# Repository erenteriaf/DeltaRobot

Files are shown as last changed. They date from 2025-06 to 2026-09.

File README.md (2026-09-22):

# Delta Robot: Vision-Guided Parallel Manipulator

A three-axis delta robot designed, machined, and programmed from scratch. A Cognex camera on the end effector reads a tic-tac-toe board, a Python game layer chooses the move, and a Siemens S7-1200 PLC executes it through closed-form inverse kinematics. The result is an autonomous robot that plays tic-tac-toe against a human.

Delta Tec Challenge, *Design and Development of Robots*, Tecnológico de Monterrey, February to June 2025. Team of six.

<!-- Replace with a photo or GIF of the physical robot playing -->
<!-- ![Delta robot playing tic-tac-toe](docs/demo.gif) -->

## System overview

```mermaid
flowchart LR
    CAM[Cognex camera] -- TCP socket --> PY[Python game layer<br/>minimax]
    PY -- S7 protocol via snap7<br/>target XYZ, gripper, conveyor --> PLC[Siemens S7-1200<br/>IK in SCL]
    PLC -- pulse trains --> M[3x NEMA 23 geared steppers]
    LS[Limit switches] --> PLC
    M --> R[Delta mechanism + pneumatic gripper]
```

Perception and decision making run on a PC; everything that touches the motors (kinematics, homing, motion commands) runs deterministically on the PLC. The PC only writes a Cartesian target and a few flags to a PLC data block.

## Mechanical design

Designed in SolidWorks and manufactured in-house on a Haas VF-4 CNC mill and a lathe.

| Subsystem | Implementation |
|---|---|
| Structure | Base, biceps, motor mounts, and end-effector platform CNC-cut from 1/2 in aluminum plate |
| Actuation | NEMA 23 steppers (3 N·m) with SPLF60 5:1 planetary gearboxes, one per arm |
| Shoulder joint | Oldham coupling into a lathe-turned aluminum shaft supported by an SHF-14 crossed-roller bearing, which carries the arm's moment loads instead of the gearbox |
| Forearms | Parallel pairs of 10 mm aluminum rods with left- and right-hand threaded M6 rod ends, so each forearm's length can be trimmed by rotating the rod |
| End effector | Pneumatic gripper and Cognex camera mounted on the moving platform |
| Safety and sensing | Roller-lever limit switch per arm for homing, emergency stop, thermomagnetic breaker |

With 1/16 microstepping and the 5:1 gearbox, each arm has 16,000 steps per revolution, a joint resolution of 0.0225°.

A static FEA of the full assembly (551 contact sets) under a 2 kg payload gave a maximum resultant displacement of about 0.12 mm.

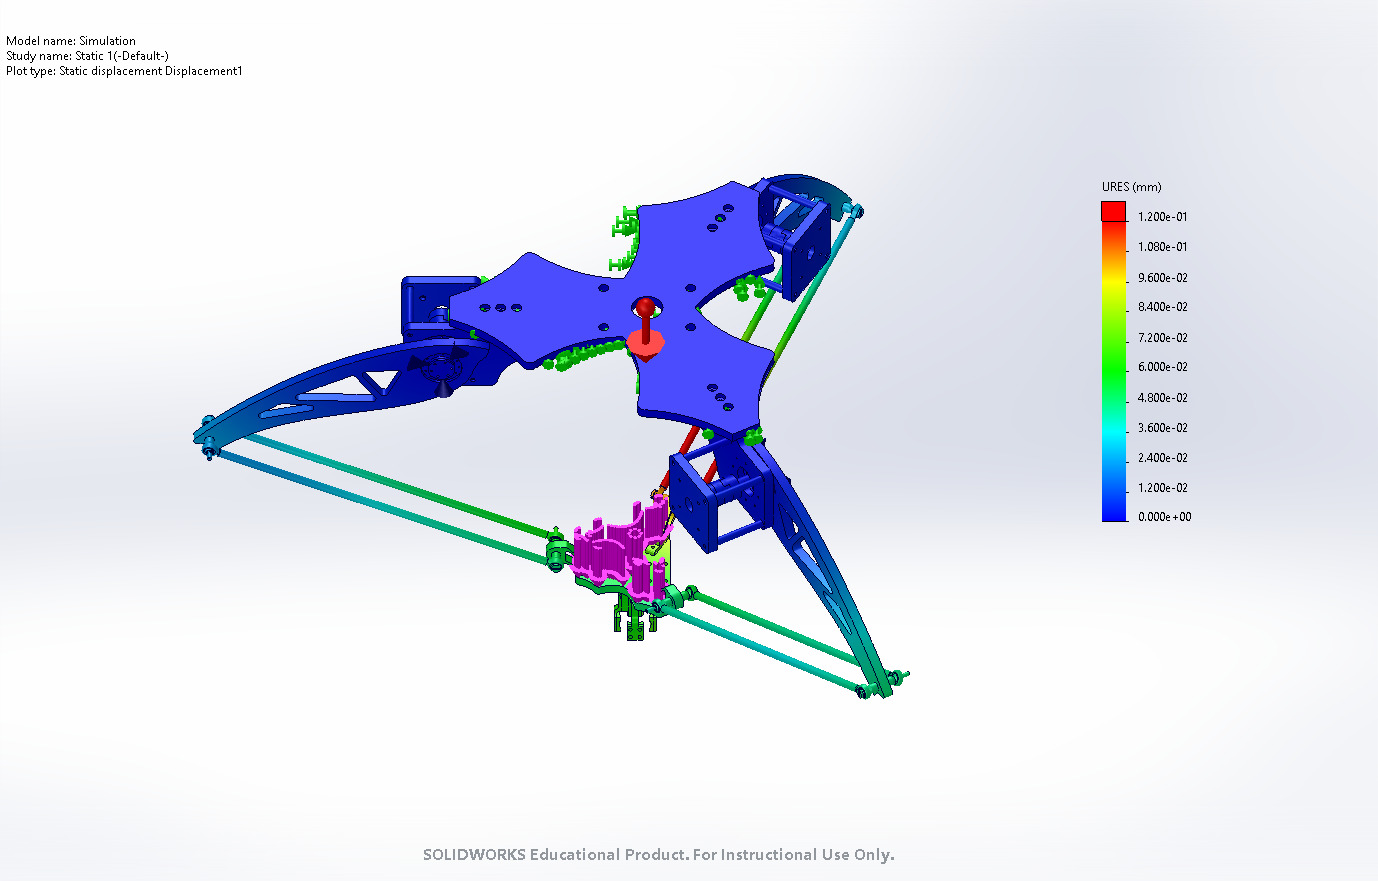
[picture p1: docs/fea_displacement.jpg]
Static FEA displacement plot


## Kinematics

| Parameter | Value |
|---|---|
| Base radius (center to biceps axis), $\rho_B$ | 215.8 mm |
| Biceps length, $l_1$ | 320 mm |
| Forearm length (rod-end center to center), $l_2$ | 476 mm |
| Platform radius, $\rho_P$ | 100 mm |

Three MATLAB models in `kinematics/`, each a runnable script that prints its result and draws the robot: `DeltaRobotInvKinematics.m`, `DeltaRobotFwdKinematics.m` and `DeltaRobotWorkspace.m`.

### Inverse kinematics

Solved in closed form, arm by arm, which is what makes it portable to a PLC scan. For arm *i*, the target platform joint is rotated into that arm's plane (0°, 120°, 240° about *z*). The forearm, a sphere of radius $l_2$ around the platform joint, cuts that plane in a circle of radius

$$\phi_i = \sqrt{l_2^2 - x_i^2}$$

where $x_i$ is the out-of-plane offset. The elbow is the intersection of this circle with the biceps circle of radius $l_1$ around the shoulder, and the crank angle follows from the elbow position:

$$\theta_i = \mathrm{atan2}\left(z_{J_i}, y_{B_i} - y_{J_i}\right)$$

Two intersections exist; the one with the smallest $y$ is the outward elbow the machine is built in. Targets where the circles do not intersect are rejected as unreachable, which is the same test the workspace sweep below is built on.

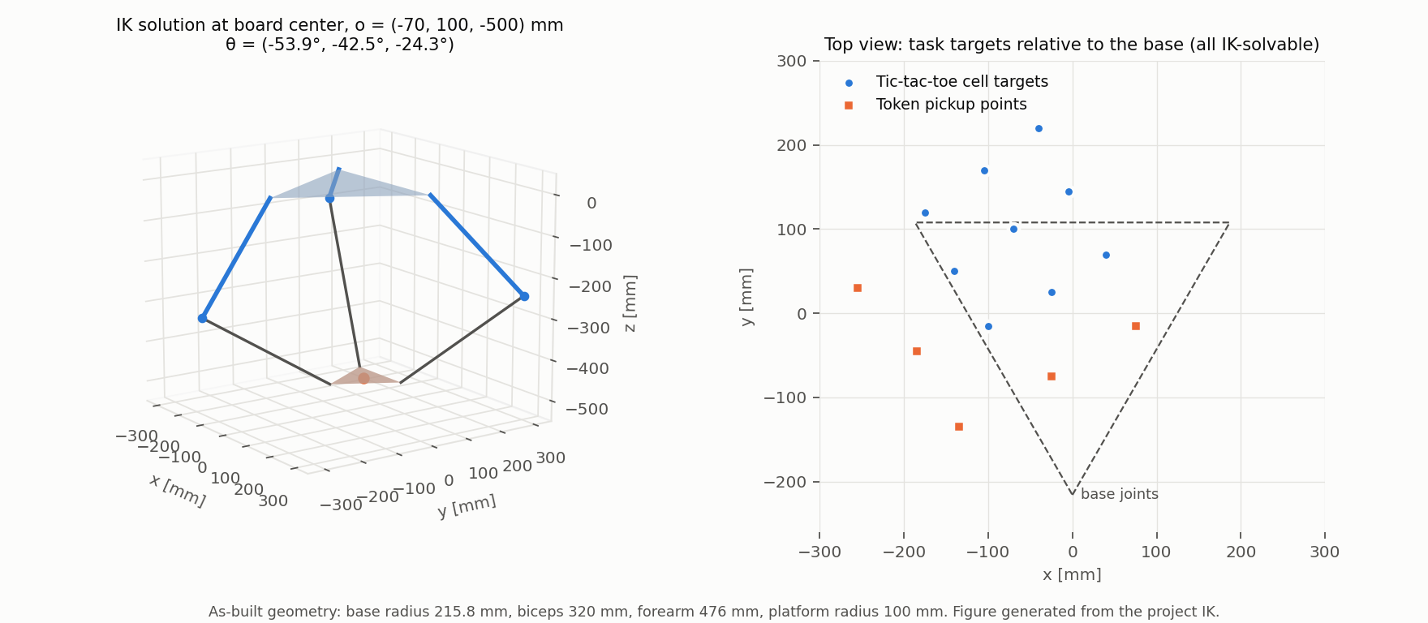
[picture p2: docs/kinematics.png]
Inverse kinematics solution at the board center


### Forward kinematics

The inverse problem: given the three crank angles, where is the platform? Shifting each elbow inward by $\rho_P$ collapses the moving platform to a single point, so the three forearms become three spheres of radius $l_2$ that intersect at the platform center. Of the two intersections, the one below the base is the physical one.

This is what fixes the reference for the whole open-loop chain: homing jogs each arm onto its limit switch, and the forward kinematics of those three switch angles, 16°, 12° and 9°, gives the Cartesian home the PLC latches, (2.59, -5.26, -139.23) mm.

### Workspace

`DeltaRobotWorkspace.m` sweeps a Cartesian grid and keeps the points the robot can actually be commanded to. Solving the loop closure is only the first of four tests, and on its own it is badly optimistic:

1. **Loop closure.** The forearm sphere must reach the arm plane, and the circle it leaves there must cut the biceps circle. This is the IK test above.
2. **Crank stops.** Homing raises each arm until it trips its limit switch, so those angles are the hard upper stop: no pose may ask an arm past 16°, 12° or 9°. Closure alone happily returns poses needing +74° on arm 2, with the biceps hanging straight down and the forearm reaching back up over it.
3. **Rod-end swivel.** Each forearm leaves its arm plane by $\beta_i = \arcsin(x_i / l_2)$, and that angle is misalignment the rod ends at both of its ends have to absorb.
4. **Serial singularity.** Biceps and forearm lined up in the arm plane, at the edge of reach, where the arm gains no velocity along the forearm.
5. **Parallel singularity.** The three forearms approaching a common plane. Their unit vectors are the rows of the platform Jacobian, so the determinant collapsing means the platform loses its stiffness and the rods take the load instead of the cranks.

Each test is a large cut. Loop closure alone claims **425 L** and lets the platform climb to *z* = -20 mm out at the rim, arms folded into poses the machine cannot hold. The crank stops and the two singularity margins bring that to 218 L, and the rod ends bring it to **133 L**: a bowl from *z* = -151 mm at its apex, directly under the base, down to *z* = -781 mm, never wider than 351 mm in radius. The apex sits just below the homed height, as it should, since the arms are against their stops there and the platform cannot rise any further.

<p align="center">Usable workspace, boundary surface</p>

### Against the envelope the cell was built to

The working volume assumed when the cell was laid out was a box, *x* and *y* within ±210 mm of the base axis and *z* from -235 mm to -655 mm. Checking it against the model is the useful test, and it disagrees in one place:

| | Assumed box | Model |
|---|---|---|
| Top of travel, on the axis | -235 mm | -151 mm |
| Top of travel, at the box corner (*r* = 297 mm) | -235 mm | -352 mm |
| Bottom of travel | -655 mm | -781 mm |
| Rod-end swivel demanded at the worst corner | not checked | 37.1° |

The floor and the width are fine, with room to spare. The ceiling is not: at the corners of that box the arms are already against their limit switches by *z* = -352 mm, so the top 120 mm of the assumed volume is only reachable near the axis. Every height the robot actually ran at, -400 mm for transits and -500 to -522 mm for the board and the token feed, sits well inside the real bowl, so the optimism never cost anything in practice.

The rod-end figure is the loose end. Holding that box takes 37.1° of misalignment at its worst corner, and `beta_max` is set to 40° to match, which is inferred from the layout rather than measured. A catalogue M6 rod end allows nothing like that, so either the parts are not standard or the joints were working well past their rating. That number is worth putting a protractor to before trusting the bowl at its widest.

The limits all sit at the top of `DeltaRobotWorkspace.m` as `theta_max`, `beta_max`, `det_min` and `ser_min`. Setting the first two to `Inf` and the margins to zero gives the geometric envelope back, which is a useful check but not a place to send the robot.

Both kinematic models were cross-checked as exact inverses of each other. The IK was then ported to Structured Text (SCL) on the PLC, including the helper routines it needs (matrix-vector products, circle intersection, `atan2`), since the S7-1200 has no linear algebra library.

## Control and autonomy

- **PLC (S7-1200, TIA Portal):** a main routine dispatches between `HOMING` and `MOVE_XYZ`. Homing jogs each arm to its limit switch and latches a known joint state. `MOVE_XYZ` runs the IK, converts the joint-angle change into relative step counts, and commands the three axes through PLCopen motion blocks (`MC_Power`, `MC_MoveRelative`).
- **PC link:** Python writes targets and flags directly into the PLC data block with `python-snap7`.
- **Vision:** the Cognex job classifies each of the nine cells and sends the result over a TCP socket.
- **Decision:** exhaustive minimax, so the robot never loses.
- **Task sequencing:** approach at a safe height, descend, grip, lift, place, return home. A conveyor feeds new tokens between turns, and a cell occupied by the opponent can be cleared before placing.

## Repository

| Path | Contents |
|---|---|
| `kinematics/` | MATLAB forward and inverse kinematics and the workspace map, with 3D visualization |
| `plc/` | Structured Text blocks running on the S7-1200: inverse kinematics, homing, axis motion |
| `pc/` | Python vision client, PLC link, and the minimax game layer |
| `cad/Subassem/` | Full delta assembly and its subassemblies (base, forearm, end effector, drive) |
| `cad/Aluminum Parts/` | Machined structural parts |
| `cad/Mechanical Elements/` | Purchased components: motor, bearings, couplings, limit switch, camera, gripper |
| `cad/NEMA_23_smart/`, `cad/M6_rod_end/` | Vendor models of the motor-gearbox unit and rod ends |
| `cad/Manufacturing/CNC/` | Part versions prepared for machining |
| `cad/Simulation/` | Static FEA study |
| `docs/` | Figures used in this README |

`plc/` and `pc/` each have their own README describing the blocks and modules they contain.

## Team and my role

| Member | GitHub |
|---|---|
| Carolina Ruiz Alonso | |
| Emiliano Rafael Rentería Flores | [@erenteriaf](https://github.com/erenteriaf) |
| Luis Ignacio Ramírez Godínez | |
| Luis Ricardo Vázquez Fernández | |
| Marco Adrián Rodríguez Gutiérrez | |
| Víctor Manuel Gil Tafolla | [@VicmanGT](https://github.com/VicmanGT) |

<!-- Confirm and edit -->
My contributions: mechanical design, part manufacturing, and the kinematic model (MATLAB), including the IK formulation later implemented on the PLC. Integration and testing were done jointly with the team.

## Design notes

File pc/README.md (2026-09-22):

# PC layer (vision and game)

Perception and decision making. The PC reads the board, picks a move, and writes
the resulting Cartesian targets and flags into the PLC data block; it never
computes joint angles.

| File | Role |
|---|---|
| `main.py` | Task sequencer. Waits for the PLC turn flag, reads the board, picks a move, then drives approach, descend, grip, lift, place and return home, with the board and token-feed coordinates tuned on the real cell |
| `client_cognex.py` | TCP client for the Cognex camera. Reads the nine cell results and thresholds each one into `X`, `O` or empty |
| `plc_connection.py` | S7 link through `python-snap7`. Typed reads and writes into `Data_block_1` at fixed byte offsets (target XYZ, turn flag, gripper, conveyor, homing) |
| `tictactoe.py` | Board state and exhaustive minimax, so the robot never loses |

## Running it

```bash
pip install python-snap7 pygame
python main.py
```

Run it from this folder: `main.py` resolves `sounds/` relative to the working
directory. The PLC is expected at `192.168.0.1` (rack 0, slot 1) and the Cognex
job at `127.0.0.1:5001`, both set at the top of their modules.

The loop triggers on the rising edge of the PLC turn flag and paces each leg of
the move with fixed delays, so a turn runs as a fixed point-to-point sequence.

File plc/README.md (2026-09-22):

# PLC control (Siemens S7-1200)

Structured Text (SCL) blocks from the TIA Portal project. Everything that touches
the motors runs here, deterministically: the PC only writes a Cartesian target and
a few flags into `Data_block_1`.

These are the block bodies as written in TIA Portal, without the declaration
headers, so they read as source rather than import directly into a project.

## Dispatch

```
main                       flags in/out, dispatches on start_play / go_home / go_out_home
├── MOVE_XYZ               target -> joint angles -> relative steps -> motion
│   ├── DELTA_INVERSE_KINEMATICS
│   │   └── COMPUTE_THETA  (once per arm)
│   │       ├── TRANSPOSE
│   │       ├── VEC_MAT_MULTIPLICATION
│   │       ├── CIRCLE_INTERSECTION
│   │       └── ATAN2
│   ├── ANGLE_2_PULSES     (once per arm)
│   ├── ACTIVATE_MOTORS
│   └── SET_ANGLES         latches the reached pose as the current joint state
├── HOMING                 jog to the limit switches
└── OUT_HOMING             jog back off them
```

## Blocks

| File | Role |
|---|---|
| `main.scl` | Mirrors the PC flags onto the gripper and conveyor outputs, then calls one of the three motion blocks |
| `move_xyz.scl` | Solves the IK for the requested point, converts each joint-angle change into a relative move, and commands the three axes |
| `delta_inverse_kinematics.scl` | Closed-form IK: base and platform points per arm, one `COMPUTE_THETA` call each |
| `compute_theta.scl` | Single arm: rotate the target into the arm plane, cut the forearm sphere into a circle of radius $\phi$, intersect it with the biceps circle, keep the outward elbow, take `atan2` |
| `circle_intersection.scl` | Intersection of two circles in the arm plane, both solutions returned |
| `atan2.scl` | Four-quadrant arctangent in degrees, since the S7-1200 has no `atan2` |
| `transpose.scl` | 3x3 matrix transpose |
| `vec_mat_multiplication.scl` | 3x3 matrix-vector product |
| `vec_sum.scl` | 3-vector sum |
| `angles_2_pulses.scl` | Joint-angle change to the relative step count for `MC_MoveRelative` |
| `activate_motors.scl` | `MC_Power` and `MC_MoveRelative` on the three axes, raises `point_reached` when all three report done |
| `set_angles.scl` | Copies the commanded angles into the current joint state |
| `homing.scl` | Jogs each arm onto its limit switch, then latches the known joint angles (16, 12, 9 deg) and the matching Cartesian home |
| `out_homing.scl` | Jogs each arm off its switch, the inverse of `homing` |

Positioning is open loop from the homed state: `SET_ANGLES` keeps the current joint
angles in the data block, and every move is commanded relative to them. The Cartesian
home latched by `HOMING` is therefore the origin of the whole chain, and is set to the
forward kinematics of the three switch angles rather than to a measured value.

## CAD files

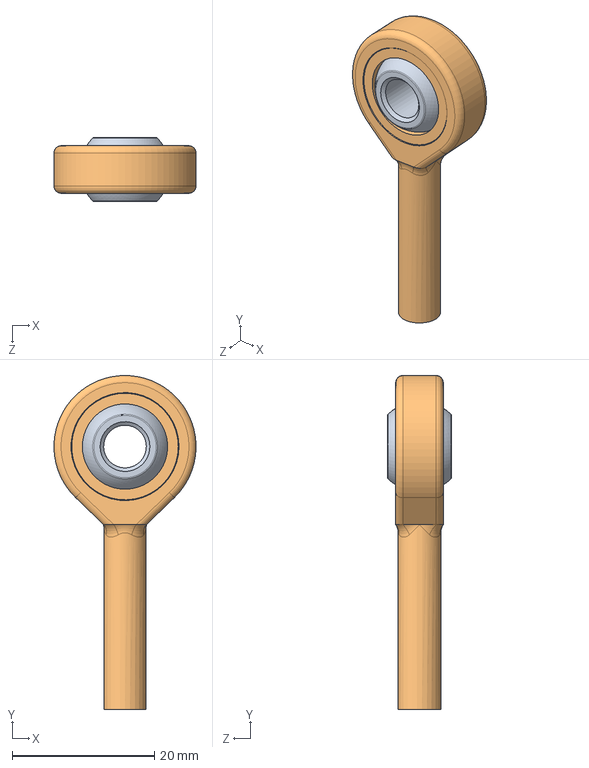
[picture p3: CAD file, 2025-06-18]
cad/M6_rod_end/SA6TK.SLDASM
20.0 x 47.0 x 9.00 mm
SA6TK_housing
SATK_ball

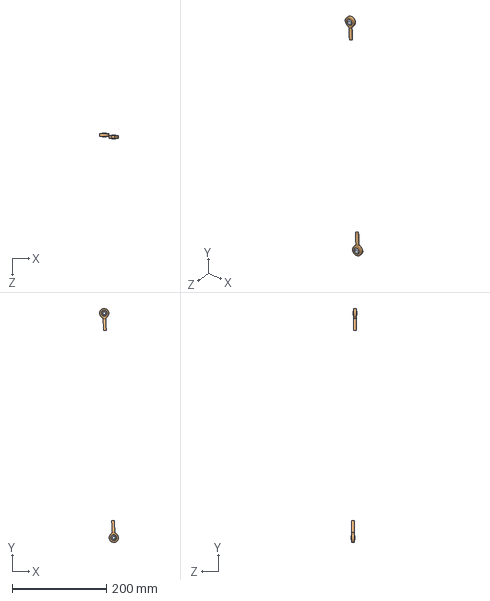
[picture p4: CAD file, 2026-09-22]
cad/Subassem/forearm_assem.SLDASM
40.2 x 495.6 x 13.2 mm
SA6TK_housing x 2
SATK_ball x 2

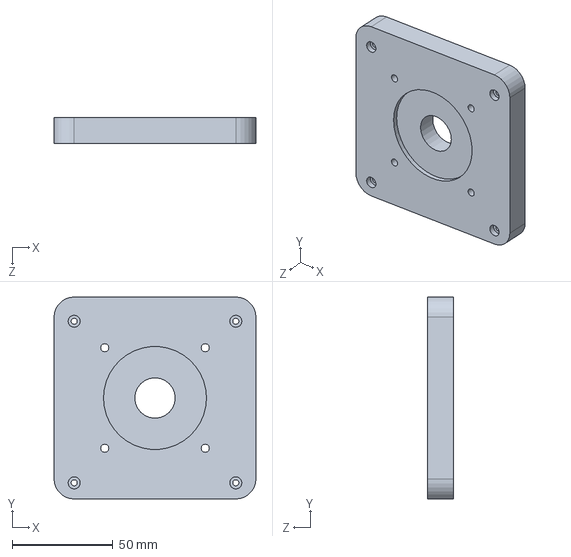
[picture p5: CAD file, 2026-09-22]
cad/Aluminum Parts/motorcoupler part1.SLDPRT
100.0 x 100.0 x 12.7 mm

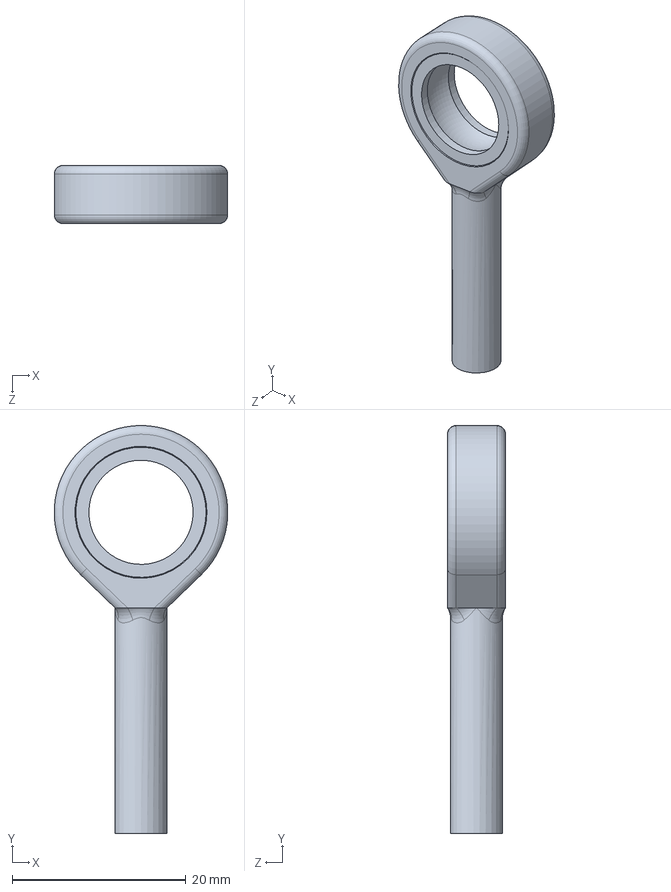
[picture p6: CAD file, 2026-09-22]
cad/M6_rod_end/SA6TK_housing.SLDPRT
20.0 x 47.0 x 6.70 mm

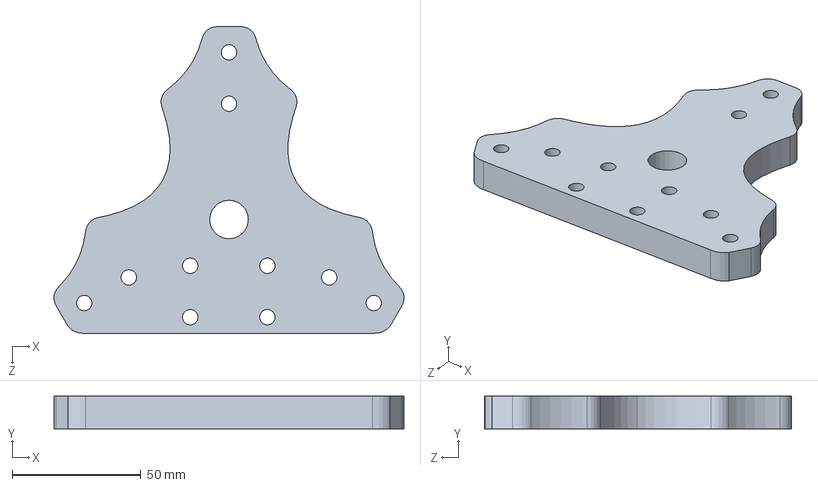
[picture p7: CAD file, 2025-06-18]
cad/Manufacturing/CNC/Bases/end effector.SLDPRT
136.1 x 12.7 x 119.3 mm

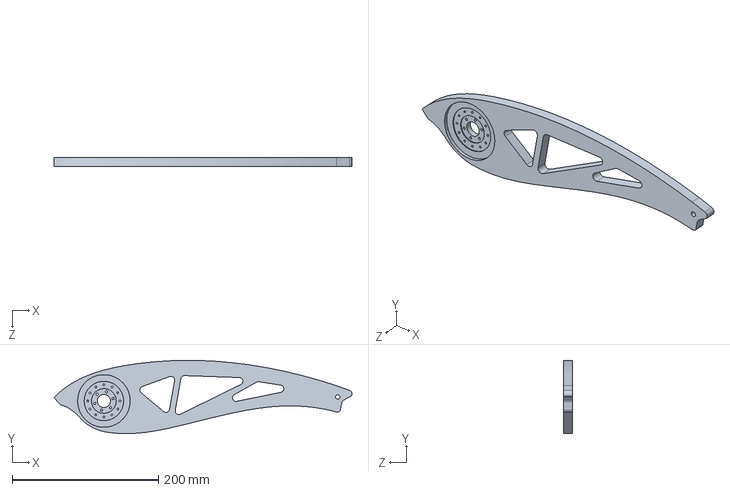
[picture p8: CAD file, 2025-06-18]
cad/Manufacturing/CNC/Brazos/bicep.SLDPRT
407.7 x 100.2 x 12.7 mm

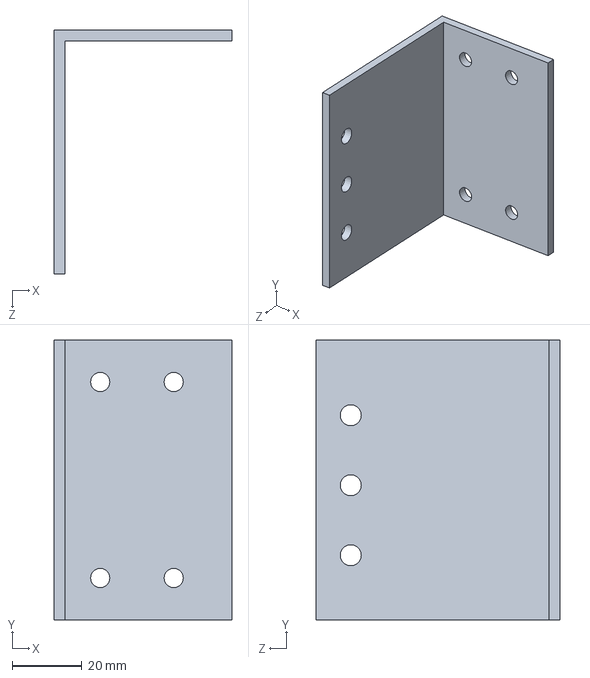
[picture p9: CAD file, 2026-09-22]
cad/Mechanical Elements/limit base.SLDPRT
50.8 x 80.0 x 69.8 mm

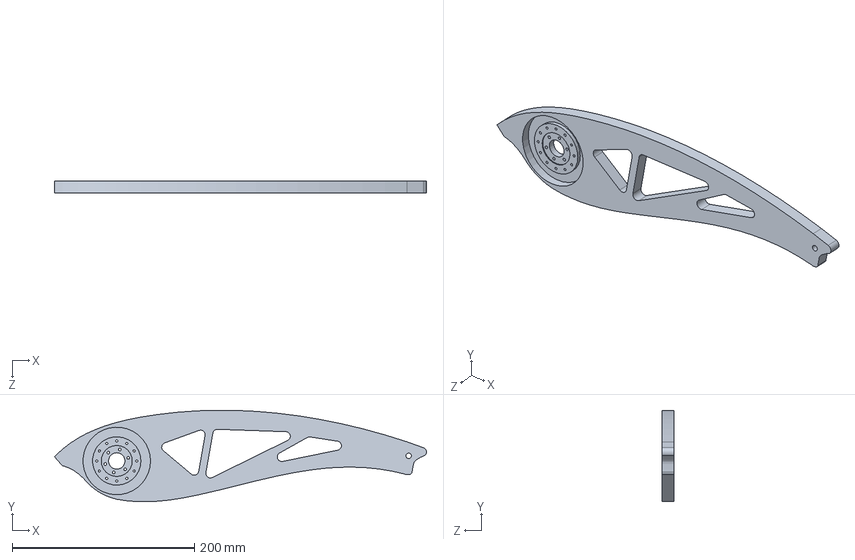
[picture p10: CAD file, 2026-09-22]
cad/Aluminum Parts/bicep.SLDPRT
407.7 x 100.2 x 12.7 mm

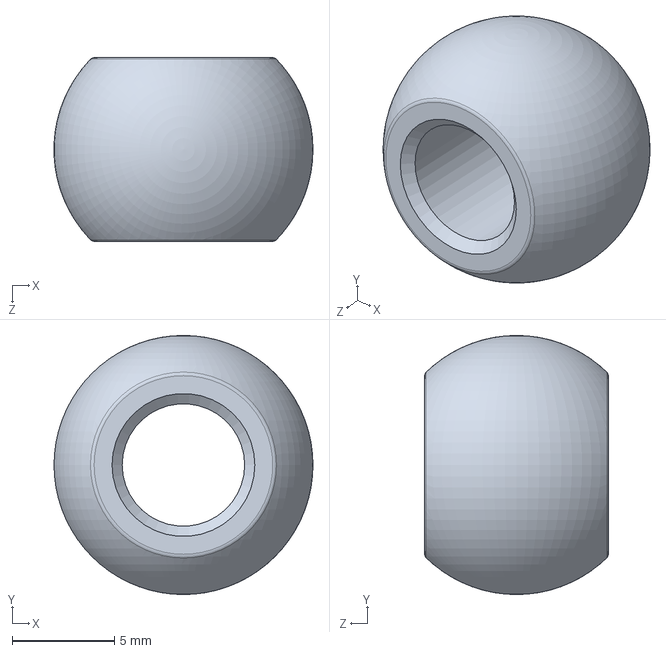
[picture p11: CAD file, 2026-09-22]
cad/M6_rod_end/SATK_ball.SLDPRT
12.7 x 12.7 x 9.00 mm

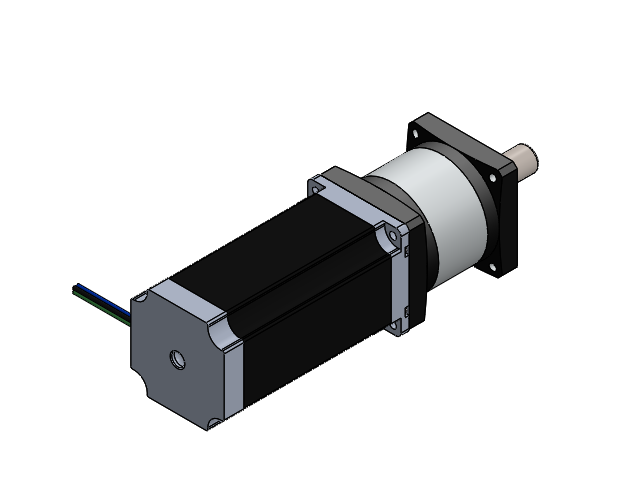
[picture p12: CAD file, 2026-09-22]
cad/NEMA_23_smart/NEMA_23_Box.SLDASM
motor_NEMA_23_SC_FJ24
gear_box_SC_FJ24

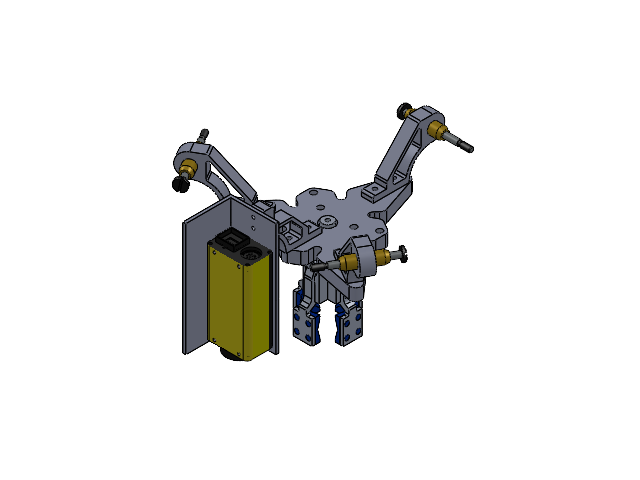
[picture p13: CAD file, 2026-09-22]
cad/Subassem/EndEffector_Assem.SLDASM
end effector
Ancla x 3
shoulder bolt M6 x 3
spacer x 6

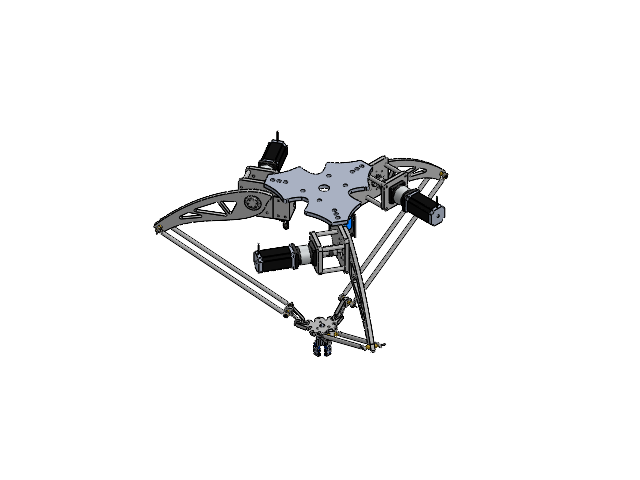
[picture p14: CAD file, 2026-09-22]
cad/Subassem/Delta_Assembly.SLDASM
delta base
motor_NEMA_23_SC_FJ24 x 3
gear_box_SC_FJ24 x 3
oldham x 3
crossrollerbearing x 3
Inner ring EFANT x 3
Shaft_simplified x 3
motorcoupler part2 x 3
coupler bar x 12
motorcoupler part1 x 3
limit base x 3
ME-8108 x 3
bicep x 3
shoulder bolt M6 x 6
spacer x 12
forearms x 6
SA6TK_housing x 12
SATK_ball x 12
end effector
Ancla x 3
Gripper chingon
Goma gripper x 4
Brazo gripper x 4

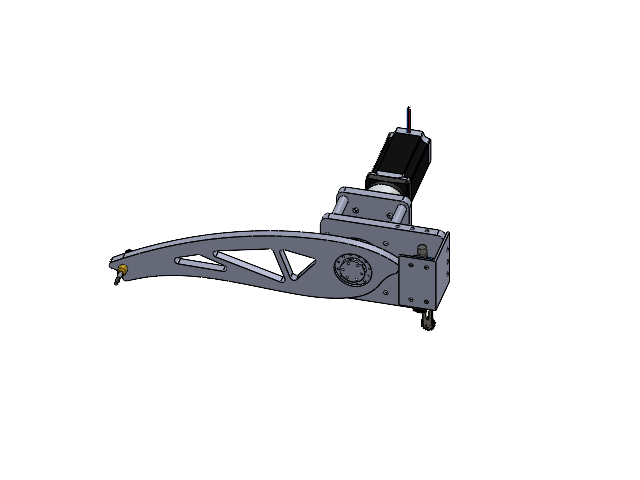
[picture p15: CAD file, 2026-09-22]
cad/Subassem/mechanical_elem_assem.SLDASM
motor_NEMA_23_SC_FJ24
gear_box_SC_FJ24
oldham
crossrollerbearing
Inner ring EFANT
Shaft_simplified
motorcoupler part2
coupler bar x 4
motorcoupler part1
bicep
shoulder bolt M6
spacer x 2

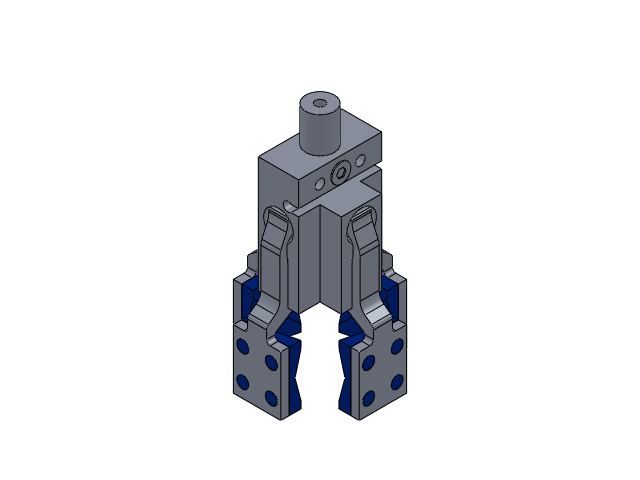
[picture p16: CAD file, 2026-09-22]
cad/Mechanical Elements/Gripper2.0.SLDASM
Gripper chingon
Goma gripper x 4
Brazo gripper x 4

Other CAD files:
cad/Subassem/Base_Assem.SLDASM
cad/Aluminum Parts/bicep_Assem.SLDASM
cad/Mechanical Elements/CrossBearing.SLDASM
cad/Mechanical Elements/DeltaAssem.SLDASM
cad/Aluminum Parts/Ancla camara.SLDPRT
cad/Aluminum Parts/Ancla.SLDPRT
cad/Aluminum Parts/Shaft.SLDPRT
cad/Aluminum Parts/Shaft_simplified.SLDPRT
cad/Aluminum Parts/angulo camara.SLDPRT
cad/Aluminum Parts/coupler bar.SLDPRT
cad/Aluminum Parts/delta base.SLDPRT
cad/Aluminum Parts/end effector coupler.SLDPRT
cad/Aluminum Parts/end effector.SLDPRT
cad/Aluminum Parts/forearms.SLDPRT
cad/Aluminum Parts/motorcoupler part2.SLDPRT
cad/Aluminum Parts/motorcoupler.SLDPRT
cad/Aluminum Parts/spacer.SLDPRT
cad/Manufacturing/CNC/Base Motores/motorcoupler part1 - copia.SLDPRT
cad/Manufacturing/CNC/Base Motores/motorcoupler part1.SLDPRT
cad/Manufacturing/CNC/Base Motores/motorcoupler part2.SLDPRT
cad/Manufacturing/CNC/Bases/delta base.SLDPRT
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

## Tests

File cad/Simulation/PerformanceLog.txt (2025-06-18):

Number of Contacts: 551
Number of contact data: 38951

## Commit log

2025-06-18 inverse kinematics
2026-09-22 Restructure repository for portfolio and add workspace model
    Top level is now kinematics/, plc/, pc/, cad/ and docs/.
    - Rename Mechanics/ to cad/ and Kinematics/ to kinematics/, dropping the
    SolidWorks lock files that had been committed
    - Add plc/ with the S7-1200 Structured Text blocks and pc/ with the Python
    vision client, PLC link and minimax game layer, mirrored from
    VicmanGT/delta-robot so the repository is self-contained (chess variant
    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
    [23hs22-2804s-hg5.SLDPRT, Ancla camara.SLDPRT, Ancla.SLDPRT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]
2026-09-22 Latch the computed forward-kinematics home in HOMING
    The Cartesian home stored by HOMING was inconsistent with the crank angles
    stored next to it: the forward kinematics of 16, 12 and 9 deg with the
    as-built dimensions gives (2.59, -5.26, -139.23), not (2.61, -13.23, -258.7).
    The old value corresponds to arms about 10 deg below horizontal, while homing
    raises them onto the switches, so it could not have come from this pose.
    Since positioning is open loop from this latch, the whole chain is referenced
    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
2026-09-22 Rewrite the workspace script in the style of the other kinematics models
    Same computation, restructured to read like DeltaRobotFwdKinematics.m and
    DeltaRobotInvKinematics.m: dimensions and inputs at the top of the script, a
    single DeltaWorkspace call, computeTheta and circleIntersection helpers keeping
    the original names and variables, per-arm calls written out instead of a loop,
    disp for the results, and one figure with the same colors and annotation boxes.
    The cross-section figure is dropped; the usable-radius table carries the same
    information. Also shortens the comments added to HOMING to match the rest of
    the SCL.
2026-09-22 Add a kinematics walkthrough with figures, and tidy the README
    - Fix the atan2 formula: GitHub's math renderer rejects \operatorname, so the
    block failed to render
    - Split the kinematics section into inverse, forward and workspace, each with
    its own figure generated from the as-built model
    - List the team alphabetically in a table with room for GitHub handles
    - Drop the limitations section and the note about where the control code came
    from
2026-09-22 Rebuild the workspace sweep around the mechanical limits
    Loop closure on its own is a bad model of where this robot can go, and the
    published workspace was roughly twenty times too large. The sweep now applies
    four more tests:
    - crank stops, since homing parks each arm against its limit switch and that
    angle is the upper end of travel. Closure alone returns poses needing +74
    deg on arm 2, biceps hanging straight down with the forearm reaching back
    up over it
    - rod-end swivel, the angle each forearm leaves its arm plane by, which the
    rod ends at both of its ends have to absorb
    - serial singularity, biceps and forearm lined up in the arm plane
    - parallel singularity, the three forearm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
2026-09-22 Use a sample pose inside the rated workspace
    The board center needs 14.8 deg of rod-end swivel, so at beta_max = 14 the
    script warned and drew no robot. Notes why next to the new default.
2026-09-22 Check the workspace against the envelope the cell was built to
    The assumed working volume, x and y within 210 mm of the base axis and z from
    -235 to -655, needs 37.1 deg of rod-end misalignment at its worst corner, so
    the catalogue 14 deg cannot be what these joints do. beta_max is set to 40 deg
    to match the layout, inferred rather than measured, and the README says so.
    That puts the usable workspace at 133 L, a bowl from z = -151 down to -781 and
    never wider than 351 mm in radius, with nothing out near the 500 mm the earlier
    figures implied. Comparing the two also finds the one place they disagree: at
    the corners of the assumed box the arms are against their limit switches by
    z = -352, so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
